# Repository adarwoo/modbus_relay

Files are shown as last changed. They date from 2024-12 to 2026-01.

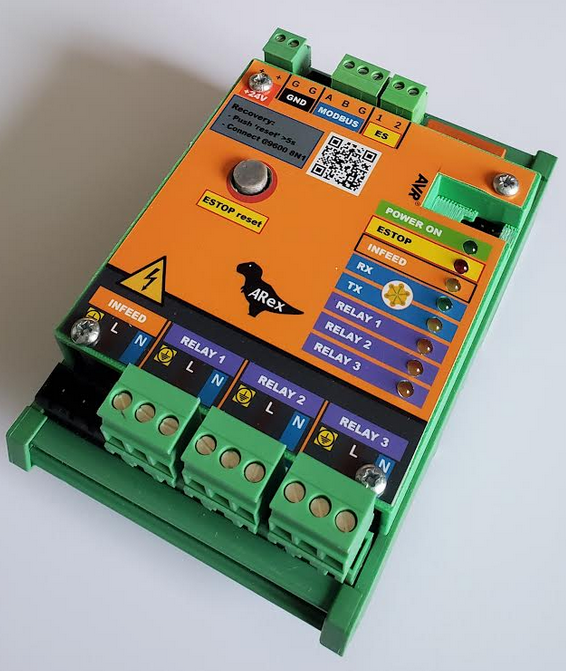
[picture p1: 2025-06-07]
cad/pictures/assembled view real.png

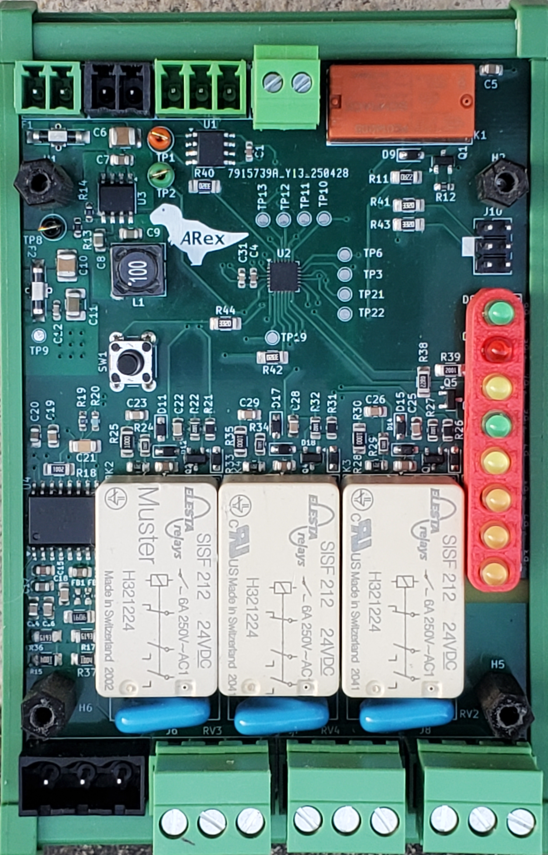
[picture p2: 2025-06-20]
cad/pictures/estop relay.png

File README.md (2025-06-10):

# Modbus Relay with EStop  #

## Introduction
This project features is a MODBUS RTU relays controller, which includes failsafe mode and an EStop.
It is aimed for industrial systems such as a CNC or equivalent.

The project comes complete with documentation, schematic, PCB, 3D part, artwork and source code.

For operational documentation, please check the complete [User Manual](docs/user_manual.md)

---

## Features summary

1. Standard DIN Rail mountable PCB
2. 3 relays - 9.4A 250VAC per output
3. Operational integrity minded
   * Uses a safety relay with force conduits and read back
   * Infeed voltage measurement with acceptable range
   * Communication watchdog
4. EStop management
   * Used for failsafe of the relay operation
      * Relay failure
      * Infeed voltage out-of-range
      * Communication loss
   * Externally controlled
     * Pulsed EStop
     * Resetable
     * Terminal
6. Operational statistics
   * Number of cycles
   * Running time
   * Fault codes

## Presentation of the hardware

<div style="text-align: center; position: relative;">
  
  
</div>

At the core of the relay is an AVR Tiny3227, an automotive grade MPU designed for harsh environment.
The MPU is clocked using the internal calibrated RC clock at 20MHz.

The relays are SISF brand used in safety critical applications.
They feature a forced conduit (so all contacts are driven by the same bar) and a dedicated read-back contact.
This allow validating the correct relay operations.
The relay are driven by small MOSFET. The read back features a contact scrubbing circuit as recommended by the manufacturer.

The modbus interface uses a RS485 driver LTC1785A (which features short protection) and transient suppressors.

The relay output features MOV suppressors for inductive loads.

The PCB can be placed in a DIN Rail PCB mount. 4 mounting screws can also be used.
A 3D cover is available to cover the whole PCBs. Together with the DIN rail mount assembly, the module should comply with IP2X.

### CAD files

The following files are available:
 * The [schematic](hw/modbus_relay.kicad.sch) edited with *KiCAD 9.1*
 * The [PCB](hw/modbus_relay.kicad.pcb) edited in *KiCAD 9.1*
 * The [BOM](hw/BOM.md) edited in *KiCAD 9.1*
 * The [Front plate artwork](hw/front_plate_graphics.svg) edited in LibreOffice Draw
 * [The front plate STL file](cad/Front%20Plate.3mf)
 * [LED holder STL file](cad/leds_spacer.STL)
 * [Spacer columns STL file](cad/3mm%2016mm.STL)
 * [Flex swtich membrane](cad/Flex%20switch%20membrane.STL)
 * [Flex retaining holder](cad/Flex%20Holder.STL)

For printing instructions, refer to [Printing the Files](#printing-the-files).

#### Printing the files

 * The case was printed in mate green PLA with PLA support material for the AVR port.
 * The flexible switch was printed in TPU.
 * The holder in black PLA.

#### Printing the front plate

 * The front was printed on an adhesive vinyl sticker at max resolution then cut to size.

> [!Note]
> You may need to adjust the dimension to account for non-linearity of the printer.

## Presentation of the software
The software is build on top of a small framework revolving around a simple reactor pattern.
The reactor allow for an arbitrary function to be notified from any context, and will execute when the CPU become available.
A simple priority system allow for reactor functions to be called in priority (to process data in a register).

A dedicated reactor pin allows measuring the worse compute time for any reactor function, which in turn, determine the worse
case latency. This allow garanteeing a real time operation throughout.
As such, the system does handle all asynchronous events in realtime with no delay, including all Modbus transaction, even at 115200 Bauds.
The jitter on the RS485 is almost null, and all replies are instantanous (4ms delay to allow for proper end of frame detection).

A python scripts is used to generates the final source for the modbus functions.

> [!TIP]
> This project could be reused for other Modbus devices. A modbus interface generator is provided that makes adding modbus commands simple.

## Application software
The application software is written in C++23 as it uses meta programming, constant expressions and concepts for efficient code.<br/>
A <i>docker</i> file is provided to create a build environment.</br>
The code fits the 32Kb flash space with plenty spare.

For build instructions, see [How to Build](#how-to-build).

## Hardware
The schematic and PCB have been edited in KiCad 9 and are supplied too.

## How to build
A docker container file is provided to recreated a full build environment.<br/>
The application can also be built in Microchip studio.<br/>
You will need a Linux shell, or WSL shell in Windows.
The tool 'gitman' is required as well as Docker. (docker-ce or else).

### Steps
```bash
# Clone this repo
$ git clone https://https://github.com/adarwoo/modbus_relay.git
$ cd modbus_relay
# Optional - install gitman
$ pipx install gitman
$ gitman update
$ make NDEBUG=1 # Optional, add ARCH=attiny1624 to suit you device
```

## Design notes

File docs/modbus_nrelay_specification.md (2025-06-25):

# ✅ Specification Requirements for Modbus N-Relay Device with EStop

## 1. Mechanical & Electrical Specifications

### 1.1 Relay and Voltage Ratings
- **SR-001**: The device shall support up to 3 relays, each rated for a maximum of 9.4A at 250V AC/DC.
- **SR-002**: The infeed voltage shall not exceed 240V (AC or DC).
- **SR-003**: The device power supply input shall operate between 15VDC and 30VDC.

## 2. Modbus RTU Interface

### 2.1 Communication
- **SR-004**: The device shall communicate over RS485 using Modbus RTU, supporting baud rates from 300 to 115200.
- **SR-005**: The communication parameters (Slave ID, baud rate, parity, stop bits) shall be configurable only in recovery mode via Modbus function 16 (Write Multiple Registers).
- **SR-006**: The device shall support Modbus function codes: 01 (Read Coils), 05 (Write Single Coil), 15 (Write Multiple Coils), 03 (Read Holding Registers), 04 (Read Input Registers), 06 (Write Single Register), 16 (Write Multiple Registers) only where specified.

### 2.2 Coil Operation
- **SR-007**: The relays shall be indexed from 0 (Relay 1) to 2 (Relay 3) in coil registers.
- **SR-008**: The device shall treat a coil written with 0xFF00 as ON (closed) and 0x0000 as OFF (open).
- **SR-009**: The failsafe state of each relay shall be OFF (open).
- **SR-010**: Writing to a disabled or faulty relay via function 05 or 15 shall return a slave device failure (code 4).

## 3. Safety & Monitoring

### 3.1 EStop Conditions
- **SR-011**: The device shall open all relays and block Modbus control when in any EStop condition.
- **SR-012**: The EStop condition shall be triggered under the following conditions:
  - Application crash
  - Power supply failure
  - Relay fault
  - Incorrect or out-of-range infeed voltage
  - Communication loss (based on watchdog timeout)
  - Modbus-issued EStop command
- **SR-013**: The device shall support 3 types of Modbus-triggered EStops:
  - Pulsed (resettable immediately after 4s)
  - Resettable (manual reset via push button)
  - Terminal (reset only via power cycle)

### 3.2 Infeed Voltage Monitoring
- **SR-014**: The device shall support configuration of acceptable voltage range between 10V to 300V (in 1/10V units).
- **SR-015**: The device shall support configuration of expected voltage type (AC 50Hz, AC 60Hz, or DC).
- **SR-016**: If voltage type or range is incorrect, the device shall enter an EStop state.
- **SR-017**: The infeed voltage type shall be reported as:
  - 0: No valid voltage (<10V)
  - 1: DC detected
  - 2: AC detected

### 3.3 Watchdog
- **SR-018**: If no Modbus command is received within the configured watchdog timeout (1–65535 seconds), the device shall trigger an EStop.
- **SR-019**: The watchdog timeout shall be configurable via holding register 40020.

## 4. Diagnostics & Statistics

- **SR-020**: The device shall store the cause and a diagnostic code for the most recent EStop event in registers 30016 and 30017, respectively.
- **SR-021**: Each relay shall maintain a counter of activation cycles (registers 30026, 30029, 30032).
- **SR-022**: The last, highest, and lowest measured infeed voltage shall be reported via input registers (30013–30015), with the ability to reset via register 40102 (write 0xAA55).

## 5. LED Behavior

- **SR-023**: On boot, all LEDs (except Modbus TX) shall turn ON for 2 seconds to test functionality.
- **SR-024**: EStop LED shall reflect fault state:
  - Off: Normal
  - On: Terminal EStop
  - 2Hz Flash: Resettable EStop
  - 2s Flash: Pulsed EStop
- **SR-025**: The Infeed LED shall:
  - Be OFF if voltage < 10V
  - Flash slowly if under-voltage
  - Flash with long ON, short OFF if over-voltage
  - Be ON if voltage is within range
- **SR-026**: The Modbus RX LED shall flash on activity or recovery mode, and TX LED shall flash only on outgoing traffic.
- **SR-027**: Each Relay LED shall:
  - Be ON if the relay is closed
  - Be OFF if open
  - Flash at 2Hz if the relay is faulty
  - Flash slowly if disabled

## 6. Relay Configuration

- **SR-028**: Each relay shall be individually configurable as:
  - Enabled with no filtering (`0`)
  - Enabled with a debounce filter between 100–60000 ms
  - Disabled (`0xFFFF`)
- **SR-029**: Configuration changes to relays shall require a device reset to take effect.

## 7. Recovery Mode

- **SR-030**: Recovery mode shall be activated by pressing the reset button for >3s.
- **SR-031**: In recovery mode:
  - Slave ID = 248
  - Baud rate = 9600
  - Serial = 8N1
- **SR-032**: Recovery mode shall maintain ongoing relay states and allow modification of communication settings.

## 8. Device Identification & Control

- **SR-033**: The device shall expose a unique Product ID (register 30001), HW version (30002), and SW version (30003).
- **SR-034**: The relay count (register 30004) shall match the actual number of relays supported (1–32).
- **SR-035**: The device shall support the following write-only control commands via register 40101–40106:
  - Set/Reset EStop
  - Zero measurements
  - Flash all LEDs
  - Factory reset
  - Exit recovery mode
  - Reset device

## 9. Fault Handling

- **SR-036**: If a relay position check fails, the EStop shall be triggered in terminal mode.
- **SR-037**: A faulty relay shall be identifiable via its LED flashing at 2Hz and input register status.

## 10. Default Settings

- **SR-038**: Default configuration on factory reset shall include:
  - Relay 1–3: Enabled, no filter
  - Watchdog timeout: 0 (disabled)
  - Infeed voltage type: AC 50Hz
  - Voltage thresholds: Lower = 100, Upper = 3000 (1/10V)

## 11. Open Requirements for Review

- **[OPEN-REQ-01]**: Behavior if voltage is exactly on threshold value (e.g., 100 or 3000). Should this be considered in-range or out-of-range?
- **[OPEN-REQ-02]**: If recovery mode times out or can persist indefinitely.
- **[OPEN-REQ-03]**: Definition of debounce filtering algorithm for relay inputs.

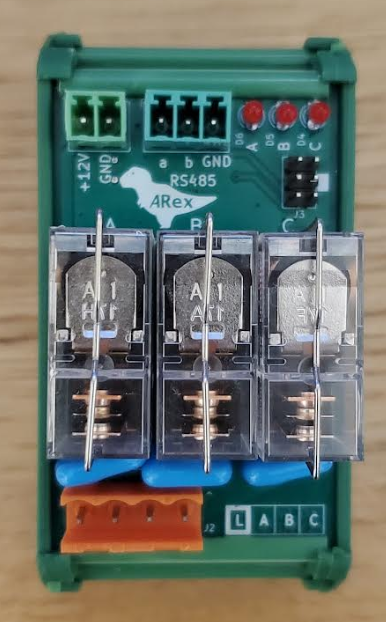
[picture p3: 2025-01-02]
cad/pictures/front.png

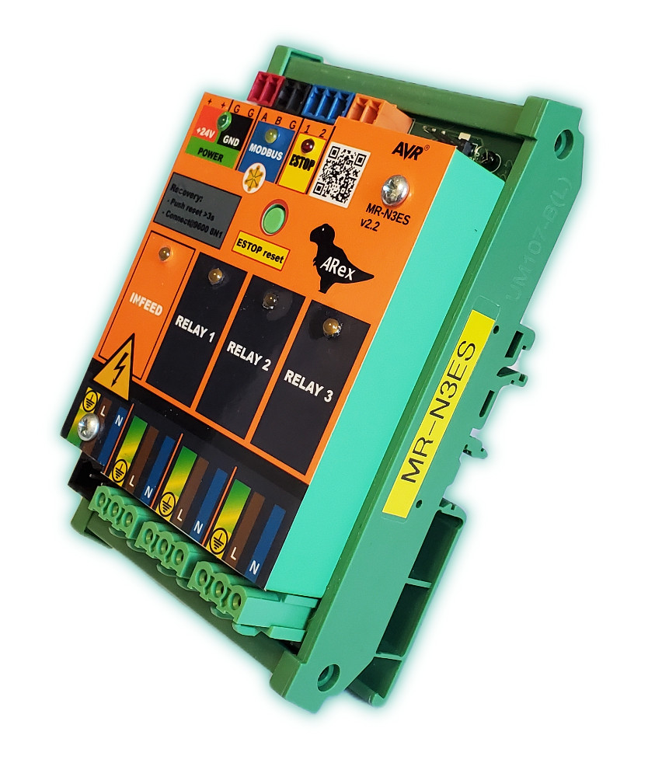
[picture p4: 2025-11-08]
docs/brochure view.jpg

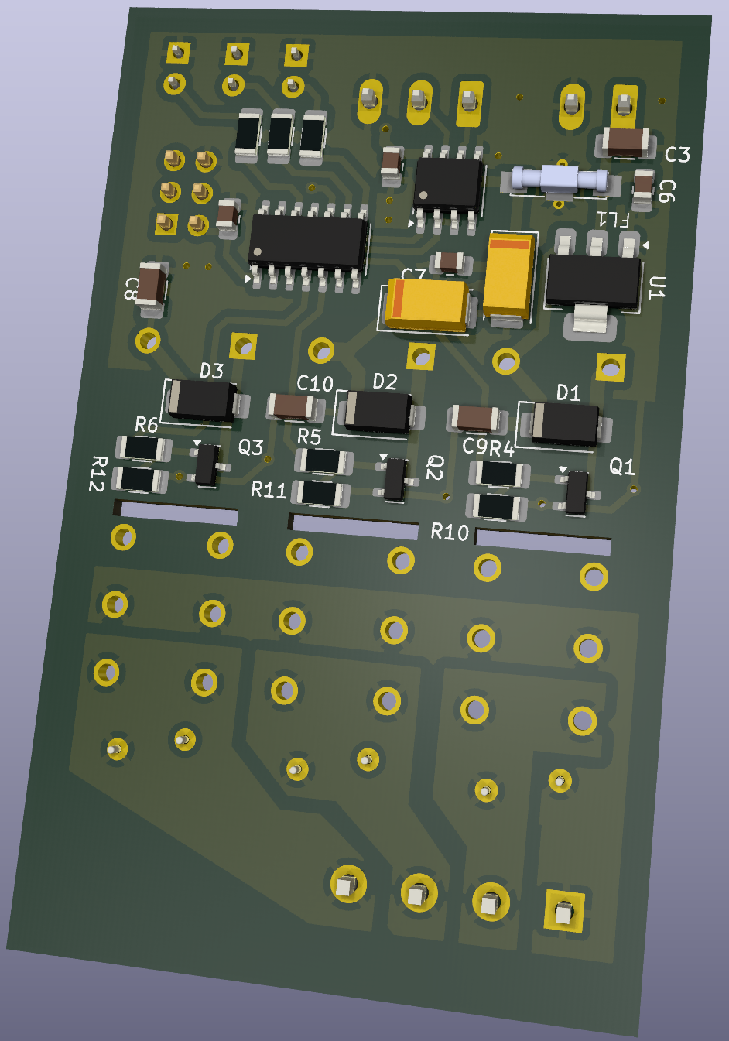
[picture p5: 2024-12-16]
cad/pictures/back.png

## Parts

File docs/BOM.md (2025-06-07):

| Reference | Qty | Value | Footprint |
|---|-----|---|---|
| C1, C4, C12 | 3 | 100n | 0603 |
| C5, C8, C14, C19, C24, C27, C30 | 7 | 1u | 0805 |
| C6, C10 | 2 | 10u 50v | 1210 |
| C7 | 1 | 220nF | 0805 |
| C9, C16, C18, C22, C23, C25, C26, C28, C29 | 9 | 100n | 0805 |
| C11 | 1 | 47u | 1210 |
| C13, C15, C17, C20 | 4 | 1n | 0805 |
| C21 | 1 | 100n | 1206 |
| C31 | 1 | 10n | 0603 |
| D1, D2, D3 | 3 | Orange 10mA | 3mm straight |
| D4, D8 | 2 | Green 10mA | 3mm straight |
| D5 | 1 | Red 10mA | 3mm straight |
| D5, D7 | 2 | Yellow 10mA | 3mm straight |
| D9, D10, D11, D12, D13, D14, D15, D16, D17, D18 | 10  | BAS16 | SOD-323 |
| D19 | 1 | SM712 | SOT-23 |
| FB1, FB2, FB3 | 3 | Ferrite | 0603 |
| FB4, FB5 | 2 | Ferrite | 0603 |
| J2 | 1 | 3 Pins Screw Header | Pitch 3.81mm<br/>Phoenix MC |
| J4, J9, J11 | 3 | 2 Pins Screw Header | Pitch 3.81mm<br/>Phoenix MC |
| J5, J6, J7, J8 | 4 | Screw_Terminal_01x03 | Pitch 5.08mm<br/>Phoenix MSTB |
| Q1, Q2, Q3, Q4, Q5 | 5 | BSS138 | SOT-23 |
| R1, R2, R3, R4, R5, R6, R7, R8 | 8 | 680 | 1206 |
| U1 | 1 | LT1785AxS8 | SOIC-8 |
| U2 | 1 | ATtiny3227-M | QFN-24 |
| U3 | 1 | LMR33630ADDA | HSOP-8 |
| U4 | 1 | AMC3330 | SOIC-16W |
| SW | 1 | Tactile switch | 6mmx6mm 9.5mm eg TL1105BF160Q |
| F1-F2 | 2 | Murata NFM61R | SMD |
| J10 | 1 | Header 2x3 | Pitch 0.1" |
| RV1-RV4 | 4 | MOV 471K | Pitch 7mm |
| H1-H4 | 4 | Spacers 3mm / Ø 16mm | To print |
| K2-K4 | 3 | Relay Muster SiSF212 24V| Through |
| K1 | 1 | Relay 5V DPDT Shrack | PE014005 |

Don't forget to add the Phoenix plugs for FB1 - FB5.

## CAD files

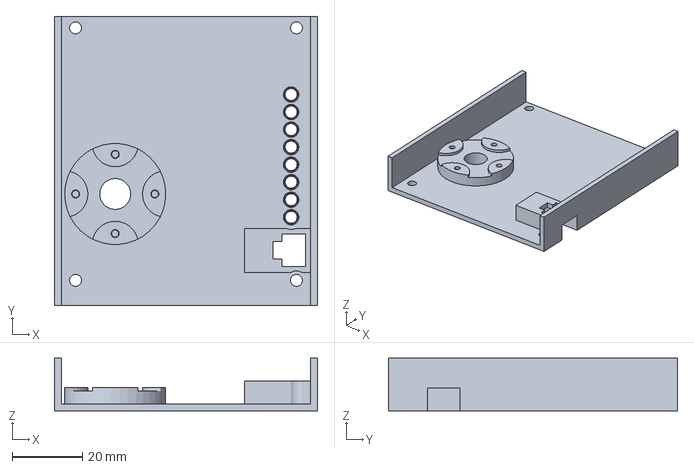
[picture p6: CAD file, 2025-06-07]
cad/3d/Front Plate.3mf
75.0 x 82.4 x 15.0 mm

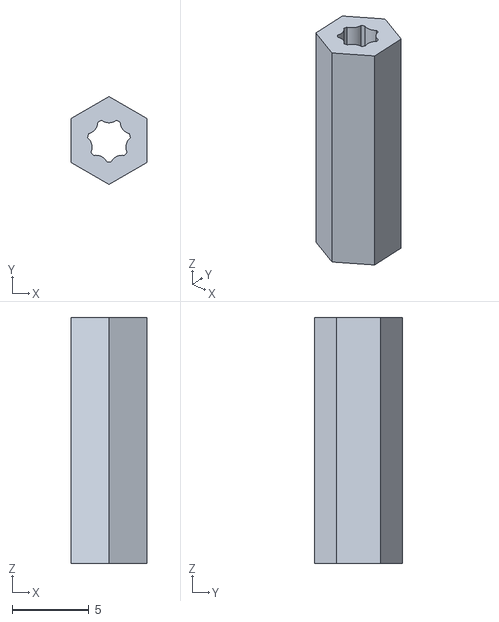
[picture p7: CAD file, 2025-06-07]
cad/3d/3mm 16mm.STL
4.95 x 5.72 x 16.0

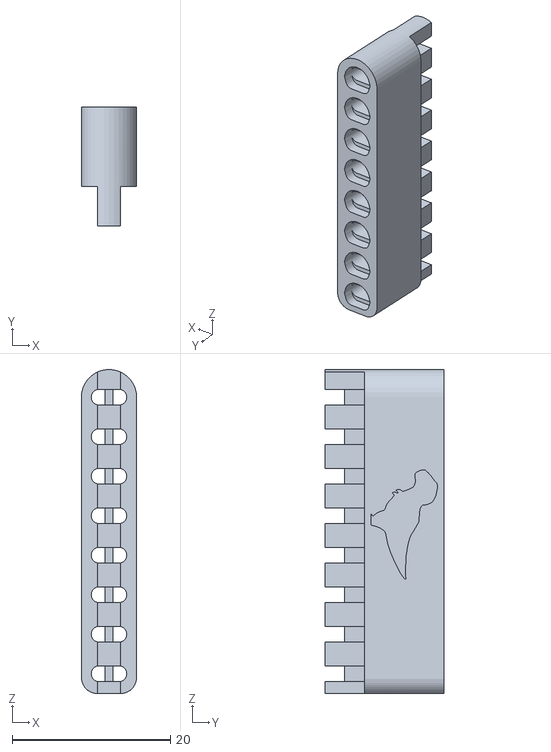
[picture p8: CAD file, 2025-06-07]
cad/3d/leds_spacer.STL
7.00 x 15.0 x 41.0

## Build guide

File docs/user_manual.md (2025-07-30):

# Modbus Relays Device with EStop <br/>**User manual**

## Introduction

This project features a MODBUS-RTU relays device with emergency stop, infeed measurements, monitoring and failsafe modes.
It is aimed at industrial systems such as a CNC or equivalent.

This document provides a description for the operations of the device.

### Device identification
The device identification is ARex_R3.
The hardware and the software are released together, the github TAG references this design uniquely.

### Features summary
This relay goes beyond a single Modbus relay and is packed with features:

1. Standard DIN Rail mountable PCB
2. 3 relays - up to 9.4A @ 250V per output
   * Individual filtering for ON and OFF cycles for each relay
3. Operational integrity minded
   * Uses safety relays with forcibly guided contacts, 10.10<sup>6</sup> operations, re-inforced isolation and position read back
   * Galvanically isolated infeed voltage measurement with acceptable range
   * Communication watchdog
4. Emergency Stop (EStop) management
   * Used to safe guard relay operations
      * Relay failure
      * Infeed voltage out-of-range
      * Communication loss
      * Application crash/corruption
   * Can be controlled by the Modbus server
     * Pulsed EStop
     * Resetable EStop with a push button
     * Terminal EStop for terminal cases
5. Operations statistics
   * Number of cycles
   * Running time
   * Fault codes
6. Diagnostics over Modbus
   * Infeed highs and lows
   * Infeed type and level
   * EStop causes and diagnostic

## Operations overview
Operations are performed over an RTU communication bus.<br/>
A push button is also featured with limited use:
* to reset EStops (when possible)
* to activate a recovery mode by placing the relay in a known state, allowing writting communication registers
<br/>
This section describes how to configure and operate the device, including its default settings, configuration mode, and reset process.

### System startup

The device starts with the EStop active (failsafe on power loss).
The device does a self-check, and starts measuring the infeed.
If all conditions are correct, the EStop is cleared. (the led turns off).
If a persistent fault is detect, the device goes in EStop.

### Relay polarity and failsafe position
The relays failsafe position is 'OFF' - that is - the contact is opened.
If the device loses power, the relays immediatly open the contacts - turning off the load.
A security prevents turning them back-on in case of crash.

The control of the relay always operates with a positive polarity, so writing '1' will close the relay - and energise the load.

### Basic operations
The relay works like any Modbus coil based devices, by writting the coil registers.
Each relay can be controlled individually, turned ON, OFF or inverted.
The relays can also be controlled in bulk.

See [Coil registers](#Coil_registers) chapter for details operations.

### Relay filtering
Filtering can be added to the relays to control the minimum ON and OFF cycles duration.
An ON filter of 2 sseconds means that the relay ON cycle will never be shorter that 2 seconds.
The same goes for the OFF filter, which guarantees a minimum duration of the OFF cycle.
Any command received during a filtered cycle will be accepted and will become the next relay state once the cycle is complete and unless overwritten by another command.

When toggling the relay, it is the projected state (the state at the end of the current cycle) that is toggled.

**Example**: a relay has an ON minimum cycle time of 5 seconds and no filter for the OFF.
* It receives a ON command. It turns ON. The cycle starts.
* Within 1 second, an OFF command is sent. This command become the next relay state, but the state of the relay remains unchanged.
* After 4 seconds, the relay turns off.
* A new ON is sent, the relay turn ON right away since the OFF cycle is not filtered.
* Within 1 second, an OFF is sent. The relay stays on.
* Another 1 second later, an ON is sent. The relay is already ON. The next state is the current state, so nothing happens.
* Another 4 seconds later, an OFF is sent. The relay turns OFF immediatly, because the ON cycle is now 6 seconds, less than the ON cycle filter duration.

> [!WARNING]
> When reading the status of a relay, the actual physical position is returned, not the projected position.

## System Health Monitoring

This device distinguishes itself from simpler models by its ability to monitor the health of the system, and to halt operations by opening an EStop relay.

The active elements being monitored and/or mesured are:
1. Device integrity
2. Modbus communications
3. Infeed voltage, that is the upsteam supply voltage
4. Proper operation of the relays

### Device integrity monitoring

The device monitors itself to guarantee proper execution.
All memories are verified:
* The flash memory integrity is verified at every boot
* The RAM is tested once on boot-up
* The EEprom storage contains a checksum and is reformatted if a corruption is detected
* The CPU power supply is monitoring by the brown-out-detector to safeguard the EEprom
* A failsafe exist which activates the EStop if the power supply was to fail
* The execution is monitored; an application crash will EStop the device

Any managed failure leads to the EStop being activated.

### Modbus communication monitoring

The device monitors the activity of the Modbus RS485 link, and through this, the health of the Modbus server.
This monitoring activity can be configured to trigger an resetable EStop.

> [!NOTE]
> The bus is considered active if commands addressed to the device are received at least once in the configured watchdog duration.

> [!IMPORTANT]
> For good operation, it is recommended to read the register 30009 (Status) periodically, like every second.
> This will keep the Modbus communication active, and all the Modbus master to detect an EStop by the relay device.

### Infeed monitoring

The module measures the infeed voltage of the relay and the type of infeed (AC vs DC).
The AC measurement is the approximate RMS value. The input signal is expected to be a 50Hz or 60Hz supply.

The last measured value, but also the lowest and highest measured values are accessible over the Modbus network.
Additional Modbus registers allow resetting those values during investigations.

The measurement can be used to trigger an EStop on:
1. Incorrect type (AC vs DC) of the infeed
2. Reverse polarity of the DC (The negative must be connected to 'N' and the positive to 'P').
3. Undervoltage : The infeed voltage is lower than a configured threshold
4. Overvoltage : The infeed voltage is higher than a configured threshold

When an infeed defect is detected, the device will open the EStop relay.<br/>
A reverse polarity is terminal.

### Relay health monitoring

All the relays are equiped with a position verification which is backed mecanically using a forced conduit.
If a relay fault is detected (open or close):
* the relay coil is de-energized, and the relay should become opened.
* the ESTop condition is trigggered in terminal mode where only a power cycle can clear the condition.

The faulty relay can be isolated by disabling it in the configuration, but it should be replaced.

### External EStop command

The modbus master can issue an EStop command. This external EStop condition can be:

* Pulsed EStop. The system will halt, but can be resumed right after
* Resetable EStop. The EStop condition is reset by pushing the 'EStop reset' push button.
* Terminal. Only a power cycle can clear the condition.

## Locate mode
The mode allows locating an relays device in setups with more than one.
When activated, the LEDs will alternate every seconds between:
 * all LEDs flash fast for 1 seconds
 * all display their normal state for the next 1 second
The locate mode is activated by a dedicated Modbus command.
It is ended by either a Modbus command, or by pressing the 'EStop reset' push button.

## Recovery mode
The recovery mode is used to recover a device with unknown setting, but also, to make changes to the communication paramters.
The recovery mode is entered by pressing the 'EStop reset' push button until the Modbus LEDs flash fast (around 3 seconds).<br/>
In these situations, the following procedure can be used:

1. Start the RelayGuardian application
2. Make sure the communication port is properly setup in the RelayGuardian
 * The connection icon should be OK
 * Issue a scan command in the RelayGuardian to make sure the RS485 adapter sends the data (Red LED)
 * If this is not the case, check the modbus is plugged correctly in the PC and the comm port is the correct one
3. If devices are identified during the scan, click the 'locate' icon one device at time to see if it is the right one
4. Else start the recovery
  1. Push the relay 'EStop reset' push button for > 3s
   * The Modbus LEDs are flashing
   * The communication values have been temporary reset to:
      | Configuration     | value             | Explanation                                    |
      |-------------------|-------------------|------------------------------------------------|
      | **Slave ID**      | `248`             | This value is reserved in the modbus standard, so no other devices should use it |
      | **Baud rate**     | `9600`            | The device talks at 9600 by default            |
      | **Serial setup**  | `8N1`             | 8bits, no parity and 1 stop bit                |

  2. In the 'Relay Guarian' application, click the 'Recovery' button
  3. Confirm proper connection
  4. In the 'RelayGuardian', click the 'Locate' button. All LEDs of relay module should be flashing fast!
   . The module is being reovered.
  5. Stop the device location mode
5. Go to the settings tabs, check the configuration, or adjust.
6. Hit the 'Synchronize' button in the relay guardian to match the relay configuration.
   . The guardian takes the relay out of recovery mode automatically.
   . You're all set!

> [!NOTE]
> The recovery mode maintains on-going relay operations.

> [!TIP]
> The recovery mode can also be ended by pressing the 'EStop reset' push button for another 3s.

## EStop mode

The device EStop relay opens the circuit when the device is in EStop condition.

The EStop condiiton is the result of:
* Detecting a internal failure (relay, crash, infeed, supply etc..)
* Through external command over Modbus

The EStop condition can be:
* Reset automatically (pulsed EStop)
* Manually reset
* Remotely reset

In all cases, the EStop condition can be read over the Modbus network.

> [!IMPORTANT]
> When the device is in both locate and EStop mode, the first push on the EStop reset clears the locate mode and the second clears the EStop.

### Relays in EStop

When the EStop is triggered by an internal condition, all the relays are **opened** (pending filtering) and no longer respond to Modbus commands (without errors).
A reset the EStop is only possible if the root cause has been cleared.
<br/>
When the EStop is triggered externally, the relays are not impacted, and it is still possible to command the relays over the modbus network.
<br/>
Example: As the infeed drops to 0 (below the threshold), all relays are opened and the EStop is activated. It is only possible to reset the EStop once the infeed voltage is back to normal.

## LEDs

The module features many LED to see the device operation and faults easilty.
All LEDs serve multiple pursposes.

### Boot

During boot, for the first 2 seconds, all LEDs are lit. This allow checking for a faulty LED.
The fault LED remains on if a persistent fault condition is detected during the auto-test.

### Locate function
To help locate a relays device, a Modbus locate command can be sent.<br/>
See [Locate mode](#Locate_mode)

The EStop reset push button can be pressed to end the locate cycle, or a new Modbus command can be sent.

For detailed LED states, see:
- [EStop LED](#estop-led)
- [Infeed LED](#infeed-led)
- [Modbus LEDs](#modbus-leds)
- [Relay LEDs](#relay-leds)

### Recovery mode
This only affects the Modbus Tx and Rx LEDs which flash at 2Hz in sync.

### EStop LED

The fault LED state is as follow:

| State | Description |
|---|---|
| Off | Normal operations |
| On | The device is terminated. A hard reboot is required. If the termination was caused by a failing relay, the correspond relay LED will flash at 2Hz |
| Flash at 2Hz | Fault detected. The fault can be cleared by pressing the ESTOP reset button.<br/>Another LED will synchronously blink to point to the fault.<br/><ul><li><b>Infeed LED</b>: Infeed fault, under or over</li><li><b>TX LED</b>: Modbus watchdog</li></ul>
| Flash once for 2s | A pulsed EStop condition was received from the modbus master |

When an EStop is is progress, a source LED is flashing fast to point to the source:
  * If a relay is at fault, the corresponding relay LED flashes
  * If the infeed supply is at fault, it will flash. Note, the LED will flash (Long on short off) it a voltage is detected.
  * The modbus Rx LED will flash to indicate the EStop was triggered remotely

### Infeed Led

The infeed LED provides visual information about the infeed voltage.

| State | Description |
|---|---|
| Off | Infeed voltage is < 10V (AC+DC) |
| On | Infeed voltage detected, and within configured range |
| Flash . . | Voltage detecting, but below the configured threshold |
| Flash _ _ | Voltage detecting, but over the configured threshold |
| Flash at 2Hz | Along with the EStop. A infeed fault was detected. |

> [!CAUTION]
> The Infeed LED is for indication only. ***You must assume voltage is present at all times***.

### Modbus LEDs

The modbus LEDs show activity on the Modbus RS485 network.

Both LEDs are overriden during boot, recovery and identification modes.

* The Rx LED shows received data on the RS485 bus. The data may or may not be addressed at the device
* The Tx LED shows data being sent from the device (as the device replies to the master)

### Relay LEDS

Each relay have a dedicated LED. The LED reports the status of the relay is corresponds to.

The LED status is as follow:

| State | Description |
|---|---|
| Off | The relay is in the OFF state |
| On | The relay is in the ON state  |
| Flash | The relay is faulty |
| Blink | Relay is disabled |

## Modbus communications and registers

The product uses [ModbusRTU over a half-duplex RS485](https://www.modbus.org/docs/Modbus_over_serial_line_V1.pdf).
It allow communication up-to 115200 baud to the relays device.

The Modbus registers are grouped into:
- [Coil Registers](#coil-registers)
- [Input Registers](#input-registers)
- [Holding Registers](#holding-registers)
- [Device Control Registers](#device-control-registers)

For communication settings, see [Communication Settings](#communication-settings).

> [!NOTE]
> By convention, all relays are indexed from 0.
> Therefore, the device relay label 'Relay 1' is indexed at 0. The relay '2' is indexed at 1 etc.

### Coil registers

The relay coils can be accessed from 0 (Relay 1) upto relay 31.
Coils can be written and read at will.

The device supports the following function code:
 * **01**: [Read coils](https://www.modbustools.com/modbus.html#function01)
<br/>Read from 1 to 32 contiguous status of coils.
<br/>Coils in the response message are packed as one per bit of a byte, 1=On and 0=Off.
<br/>If the requested quantity of coils are not a multiple of 8, zeros are padded in the final byte.
 * **05**: [Write single coil](https://www.modbustools.com/modbus.html#function05)
<br/>Write a single output to either On (1) or Off
 * **15**: [Write multiple coils](https://www.modbustools.com/modbus.html#function15)
<br/>Force each coil in a sequence of coils to either On or Off

> [!IMPORTANT]
> Relays operations are not impacted by the EStop
> Unless a relay is faulty or disabled, a command of that relay will always be executed, but could be delayed by one of the relay cycle filters

> [!WARNING]
> Attempts to write individually a disabled relay with the function <b>05</b> will generate a <i>slave device failure (4)</i> error.
> Attempts to turn ON a disabled or faulty relay as part of the function **15** will also generate a <i>slave device failure</i> error.
> You can still use function **15** providing that the faulty/disabled relay is commanded to OFF.

#### Detail of the function 05 : Write single coil

The following values can be used:

| Value | Meaning |
|---|---|
| 0x0000| This specific 16-bit value is the Modbus standard representation for "OFF". |
| 0xFF00| This specific 16-bit value is the Modbus standard representation for "ON" when writing to a coil. |
| 0xAA00| This value toggles the coil at then end of the cycle |

### Input registers

Input registers are read-only registers used to report information about the device.
The registers have been grouped so they can easily be accessed.
Reserved values reads as 0, therefore, it is possible to read them all at once.

Only the function **04**: [Read input registers](https://www.modbustools.com/modbus.html#function04) is supported to read registers.

> [!WARNING]
> Make sure to issue function 04: Read input registers when reading input registers and not function ~~**03: Read Holding Regsiters**~~, as the memory of both types overlaps.

#### Device Identification

This registers provides details about the device in use.

| Modbus Address | Hex value | Access | Description | Value(s) |
|---|---|---|:---:|---|
| 30001 | 0x0000 | R | Product ID | MSB=device Identification code <sup>1</sup><br/>LSB=Number of relays <sup>2</sup> |
| 30002 | 0x0001 | R | HW version | MSB=minor, LSB=major |
| 30003 | 0x0002 | R | SW version | MSB=minor, LSB=major |
| 30004 | 0x0003 | R | Number of relays | UINT16<br/>1-32 |
| 30005–30008 | 0x0004–0x0007 | R  | *Reserved* | |

* <sup>1</sup> EStop relay code=0x37. Simple modbus code=0x36.
* <sup>2</sup> A 3 relays device would be 0x3703. A 32 relays device would be 0x3720.

#### Status & Monitoring

| Modbus Address | Hex value | Access | Description | Values |
|---|---|---|---|---|
| 30009 | 0x0008 | R | Current status | <ul><li><b>0</b>: Device is operational</li><li><b>1</b>: Device is in EStop.<br/>A reset is possible</li><li><b>2</b>: Device in terminal EStop</li></ul> |
| 30010 (+1) | 0x0009 (+1)| R | Running minutes | UINT32<br/>0-2<sup>32</sup>-1 |
| 30012 | 0x000B | R | Actual infeed voltage type  | Reports the type of infeed voltage detected<br/><ul><li><b>0</b>: Measured AC/DC voltages are below 10V</li><li><b>1</b>: DC</li><li><b>2</b>: AC</li></ul> |
| 30013 | 0x000C | R | Current infeed voltage | 1/10 volts<br/>0-3000 |
| 30014 | 0x000D | R | Infeed highest voltage | Returns the lowest measured infeed voltage until now in 1/10th of volts.<br/>This value can be reset with the command: - [40102 - Reset measurements](#device-control-registers) |
| 30015 | 0x000E | R | Infeed lowest voltage | Same as 30014, but returns the lowest |
| 30016 | 0x000F | R | Last or on-going EStop root cause | <ul><li><b>0</b>: Normal<br>No EStop occured since power-up</li><li><b>1</b>: Relay<br/>A relay fault as detected<br/></li><li><b>2</b>: Modbus<br/>The communication watchdog reported a lack of communication</li><li><b>3</b>: Infeed voltage type<br/>An ncorrect voltage or voltage type was detected<br/></li><li><b>4</b>: Infeed voltage under<br/>The voltage has gone below the configured threshold</li><li><b>5</b>: Infeed voltage over<br/>The voltage has gone over the configured threshold</li><li><b>6</b>: Command<br/>A modbus command was issued to lace the device in EStop</li><li><b>7</b>: Application crash<br/>The device is recovering from an application crash</li></ul><br/>This register and the diagnostic code operate as a pair. They are not cleared when the EStop is reset, allowing for post crisis diagnostic, or checking the cause of pulsed resets. |
| 30017 | 0x0010 | R | Diagnostic code | Diagnostic code of the EStop condition<br>The content value depends on the EStop root cause:<ul><li><b>normal</b><br/>0</li> <li><b>Relay</b><br/>Holds the faulty relay zero based index number.</li> <li><b>Modbus</b><br/>The timeout in seconds</li> <li><b>Infeed (all of them)</b><br/>0xFFFF if the voltage type is incorrect, else the triggering voltage in 1/10V</li> <li><b>Command</b><br/>Contains the EStop control value</li> <li><b>Application crash</b><br/>0xDEAD</li></ul>|
| 30018–30024 | 0x0011–0x0017 | —  | *Reserved* | |

#### Relay Diagnostics & Statistics

The status of each relays is accessible, and well as their indivual number of cycles.
A cycle is defined as a change of a relay state during operation (exclude powerloss transitions).
<br/>
The address space is structured to expand up to 32 relays for other variants of devices.

| Modbus Address | Hex value | Access | Description | Values |
|---|---|---|:---:|---|
| 30025 | 0x0018 | R | Relay 1 diagnostic | 0=OK<br/>1=Faulty<br/>2=Disabled |
| 30026-30027 | 0x0019-0x001A| R | Relay 1 number of cycles | UINT32<br/>0-2<sup>32</sup>-1 |
| 30028 | 0x001B | R | Relay 2 diagnostic | 0=OK<br/>1=Faulty<br/>2=Disabled |
| 30029-30030 | 0x001C-0x001D| R | Relay 2 number of cycles | UINT32<br/>0-2<sup>32</sup>-1 |
| 30031 | 0x001E | R | Relay 3 diagnostic | 0=OK<br/>1=Faulty<br/>2=Disabled |
| 30032-30033 | 0x001F-0x0020| R | Relay 3 number of cycles | UINT32<br/>0-2<sup>32</sup>-1 |

> [!WARNING]
> Reading passed the last supported relay will generate a **illegal data address** error.

> [!TIP]
> For generic software, the number of available relays can be read in input registers 30004.

### Holding registers

Holding register contain values can be read or written. The hold configuration details.
They are grouped by functions.
It is possible to read all the holding registers with 1 command as the reserved values will read as one.
Writing these registers is restricted to prevent mis-behavious.

> [!WARNING]
> Reserved values cannot be written and will generate an error.

#### Supported function codes

The following function codes are supported:

* **03** - [Read Holding Registers](https://www.modbustools.com/modbus.html#function03)
<br/>Reads the values of one or more holding registers.
<br/>Commonly used to retrieve configuration or control values stored in the device.
* **06** - [Write Single Register](https://www.modbustools.com/modbus.html#function06)
<br/>Writes a single value to a specific holding register.
<br/>Used for updating configuration or control parameters.
* **16** - [Write Multiple Registers](https://www.modbustools.com/modbus.html#function16)
<br/>Writes a whole configuration group at once. This is only available for writting the communication settings.

> [!WARNING]
> Do no issue the function 04: Read input registers when reading holding registers as the memory addresses of both types overlaps.

Other functions codes such as 23 ( Read/Write Multiple Registers) are not supported.

#### Communication Settings

This group of registers allow configuring the communication settings of the relay.

> [!IMPORTANT]
> These registers are <ins>write protected</ins>.
> You must activate the 'recovery' mode to change them, by pressing the 'EStop Reset' button for more that 3 seconds.

> [!NOTE]
> Function ~~**06: Write single register**~~ is not availble for this group.
> You must use the command **16 - Write Multiple Registers**, writting registers 40001 to 40004 at once.
> Once a write is done, the device comes out of recovery mode and applies the changes right away.

| Modbus Address | Hex Value | Access | Description | Factory value | Values |
|---|---|---|---|---|---|
| 40001 | 0x0000 | RW<sup>1</sup> | device address | 44 | [1-247] |
| 40002 | 0x0001 | RW<sup>1</sup> | Baud rate selection | 5 | 0=300<br/>1=600<br/>2=1200<br/>3=2400<br/>4=4800<br/>5=9600<br/>6=19200<br/>7=38400<br/>8=57600<br/>9=115200 |
| 40003 | 0x0002 | RW<sup>1</sup> | Parity | 0 | 0=None<br/>1=Odd<br/>2=Even |
| 40004 | 0x0003 | RW<sup>1</sup> | Stopbits | 1 | 1=1 Stop bit<br/>2=2 stop bits |
| 40005–40008 | 0x0004–0x0007 | R  | *Reserved* | | |

<sup>1</sup>Writable only in recovery mode

#### Power Infeed Configuration

| Modbus Address | Hex Value | Access | Description | Factory Value | Values |
|---|---|---|---|---|---|
| 40009 | 0x0008 | RW | Infeed voltage type | 1 | 0=DC<br/>1=AC |
| 40010 | 0x0009 | RW | Infeed lower voltage threshold | 100 | 1/10 volts [100-3000] |
| 40011 | 0x000A | RW | Infeed upper voltage threshold | 3000 | 1/10 volts [100-3000] |
| 40012–40016 | 0x000B–0x000F | R  | *Reserved* | 0 | |

> [!WARNING]
> Registers 40009 to 40011 must be written together using command **16**.
> Function ~~**06: Write single register**~~ is not availble for this group.
> An illegal_data_value error (code 3) will be returned if (40011 - 40010) < 10

#### Safety Logic Configuration

Some of the monitored values can optionally control the EStop. It is also possible to set the behaviour of each relay on these optional EStop conditions.

| Modbus Address | Hex Value | Access | Description | Factory Value | Values |
|---|---|---|---|---|---|
| 40017 | 0x0010 | RW | Activate EStop on undervoltage | 0 | 0=no<br/>1=yes |
| 40018 | 0x0011 | RW | Activate EStop on overvoltage | 0 | 0=no<br/>1=yes |
| 40019 | 0x0012 | RW | Activate EStop on incorrect type of supply voltage<br>Example: AC detected with DC configured | 0 | 0=no<br/>1=yes |
| 40020 | 0x0013 | RW | Activate EStop on number of seconds without modbus frame received | 0 | 0=off<br/>[1-65535] Number of seconds |
| 40021 | 0x0014 | RW | Mask to open relays on electrical infeed fault.<br/>When a infeed fault is detected (undervoltage, overvoltage or incorrect voltage type), the projected relay state<sup>1</sup> is opened or left unchanged based on this value.<br/>A bit at 1 in the mask indicates the relay should open on a fault detection. The lsb (bit 0) masks the relay at index 0, the msb (bit 15) masks the relay at index 15 | 0 | 0-0xFFFF<br/><br/>Example:<br/>0: No relays are affected<br/>5 (binary 110): Relays at position 1 and 2 are set to open<br/>0xFFFF: All relays are set to open |
| 40022 | 0x0015 | RW | Mask to open relays on modbus communication loss fault<br/>When a loss in communication is detected, the relay projected state<sup>1</sup> is opened is left unchanged with this value. | 0 | See 40021 |
| 40023–40024 | 0x0016–0x0017 | R  | *Reserved* | | |

<sup>1</sup>The projected state is the state of a relay once the on-going filter cycle is complete

> [!WARNING]
> The registers must be written individually. The command **16** is not supported.

#### Relays Configuration

This group allow configuring the individual relays.

| Modbus Address | Hex Value | Access | Description | Factory default | Values |
|---|---|---|---|---|---|
| 40025 | 0x0018 | RW | Relay 1 config | 0=Enabled, no filter | msb bits [15-8] are for the ON filter<br/>lsb bits [7-0] are the OFF filter<br/>The value 0xFFFF disables the relay.<br/><br/>The ON and OFF filters values are given in 1/10 of seconds from 0 to 254 (0 to 25.4s)<br/><u>Example</u>: 0x0132=The On state is guaranteed to last at least 100ms, whilst the OFF state is guaranteed to last at least 50 x 1/10s = 5s after a ON. See relay operations. |
| 40026 | 0x0019 | RW | Relay 2 config | 0=Enabled, no filter | Same as relay 1 config |
| 40027 | 0x001A | RW | Relay 3 config | 0=Enabled, no filter | Same as relay 1 config  |
| 40025+N<sup>1</sup> | 0x0018+N| RW | Relay N config | 1=Enabled, no filter | Same as relay 1 config |

<sup>1</sup> N is the relay index [0..(Number of relay-1)]

> [!WARNING]
> The registers must be written individually. The command **16** is not supported.

> [!WARNING]
> Read or writing a non-supported relay will generate an error.

### Device control registers

These register share the holding registers mapping address space but are write-only.
This group of register allows controlling the EStop and the device device.

> [!NOTE]
> These registers are write only.
> The function ~~**03: Read multiple registers**~~ is not availble for this group.
> Function ~~**16 - Write Multiple Registers**~~ is not available.
> The registers must be written individually.

| Modbus Address | Hex Value | Access | Description | Values |
|---|---|---|---|---|
| 40101 | 0x0064 | W | Set/Reset the EStop | ESTOP_CTRL<br/>See note <sup>1</sup>|
| 40102 | 0x0065 | W | Zero measurements. Allow re-measuring min and max | 0xAA55  |
| 40103 | 0x0066 | W | Identify the device. Fast flash all the LEDs to identify the device | 0 = Turn off<br/>1 = Turn on |
| 40104 | 0x0067 | W | Reset configuration to factory default and reboot  | 0x178C |
| 40105 | 0x0068 | W | Exit recovery mode and apply comms settings  | 0xAA55  |
| 40106 | 0x0069 | W | Reset the device | 0xAA55  |

**Note <sup>1</sup>** : See the format below

#### EStop control

The following table documents the type **ESTOP_CTRL** used to control the EStop.

| Byte | Function | Values |
|---|---|---|
| MSB  | Type of EStop | 0x00 : Reset the EStop if possible. Returns an error if the EStop could not be reset<br/>0x11 : Pulsed EStop. Create a 4 second EStop pulse<br/>0x22 : Resetable EStop mode. The EStop can be reset by pushing the EStop reset button<br/>0xFF : Terminal EStop. Only a reset will clear the ESTop (Register 40103) |
| LSB | Diagnostic code | A code can be applied to allow investigating the cause of EStop/Reset.<br/>Values: <0-255> |

## Electrical and mecanical characteristics

For relay data, refer to the datasheet of the [SiSF2 relay](https://www.ermec.com/catalogos/2021/ELESTA/sisf2_-_en.pdf) for detailed data.
Note that both contacts of the relay are paired as one.
The key information is summ

### Electrical characteristics

| Item | Min | Max |
|---|-----|-----|
| Device supply voltage | 18 VDC | 30 VDC |
| Infeed voltage | - | 250V (AC/DC) |
| Relay contact current | - | 9.4A (AC/DC) |

### Contact life

| Item | Value |
|---|---|
| 230VAC, 1A | 800k |
| 230VAC, 9.4A | 100k |
| 24VDC, 0.5A | 2M |
| 24VDC, 9.4A | 300k |

## Troubleshooting

### Cannot Communicate with device
- If the modbus LEDs are flickering, make sure the RelayGuarian and relay share the same settings.
- Active the recovery mode on the device and in the RelayGuardian
- If no communication is established, check the serial adapter communication port
- Check the wriring. Modbus pins cannot be swapped.

### Lost Device ID
1. Send a valid broadcast frame to enter configuration mode.
2. Use the default Device ID (`0`) to reset the device via the reset register.

### Relay Does Not Respond
- Check the watchdog timeout setting to ensure it isn’t triggering prematurely.

---

## FMEA – Modbus Relay Board for CNC Safety

This FMEA analyzes potential failure modes of a Modbus-controlled relay board designed for CNC safety, including load control and emergency stop (E-stop) functionality.
Any failure should result in the CNC stopping by letting go of the estop switch.
<br/>**Note**: The estop must be checked once at the start of operations. This step is done by the Masso CNC device. This relay estop contact is Normally Opened. So when the CNC starts, the relay would be open.
If the relay was to close **after** the Masso had booted, this could be considered an estop test.
Therefore, the relay must be started well before the Masso. This is the case (100ms vs 10s).

The top events to consider are:
1. Lack of dust extraction clogs the work and leads to the cutter breaking.
The operation is done in normally closed and protected condition to safeguard the operator.
Mecanical damage only.
2. Lack of cooling of the spindle leads to spindle overheat.
NTP sensor on the spindle should detect the overheat if wired. Else, the spindle could be damaged.
A fire is unlikely.

| Function | Failure Mode | Effect of Failure | Cause(s) | Detection Method(s) | S | O | D | RPN | Recommended Action(s) |
|---|---|---|---|---|---|---|---|-----|---|
| Control Load Relays  | Relay not switching | Load not powered leading to CNC or cutter damage | Relay failure, dry joint | Feedback circuit | 8 | 4 | 3 | 96  | Add redundant relay check, use industrial-grade relays |
| Control Load Relays  | Relay stuck ON | Unsafe load activation | Relay contact welding | Feedback circuit | 9 | 3 | 4 | 108 | Use a forced conduit relay and read back the status of the relay  |
| E-Stop Relay | E-stop not triggered | CNC continues in unsafe state | Logic fault, relay failure | Self-test, watchdog | 10| 2 | 3 | 60  | Use safety-rated relay, periodic self-test |
| Power Monitoring | Under/over voltage undetected | Damage to CNC or relay | Sensor failure, ADC error | Voltage threshold check | 9 | 3 | 4 | 108 | Add voltage sensing, calibration check |
| Power Converter | Converter fails | Relay board unpowered, failsafe triggers | Component failure | Relay state monitoring | 7 | 4 | 2 | 56  | Use robust converter, thermal protection. =<br/>Power the estop relay from the mains power |
| Modbus Communication | Loss of communication | E-stop triggered, CNC halts | Cable fault, EMI, software crash | Timeout watchdog | 6 | 5 | 2 | 60  | Loss of comms indicates the bus is damaged or the master has crashed. esop. |
| Test of the esop switch | estop relay opens and close cycle is considered a estop switch test  | False E-stop test | Non cold reboot of the firmware | Analysis of the reboot cause | 8 | 3 | 3 | 72  | Do not allow the modbus board to reboot |

### Legend
- **S (Severity)**: 1 (low) to 10 (catastrophic)
- **O (Occurrence)**: 1 (rare) to 10 (frequent)
- **D (Detection)**: 1 (certain detection) to 10 (undetectable)
- **RPN (Risk Priority Number)**: S × O × D

### Summary
Focus should be placed on:
- Improving detection of stuck or failed relays
- Enhancing voltage monitoring redundancy
- Ensuring robust communication and feedback diagnostics

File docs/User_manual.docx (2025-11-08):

Modbus Relays Device with EStop

User Manual

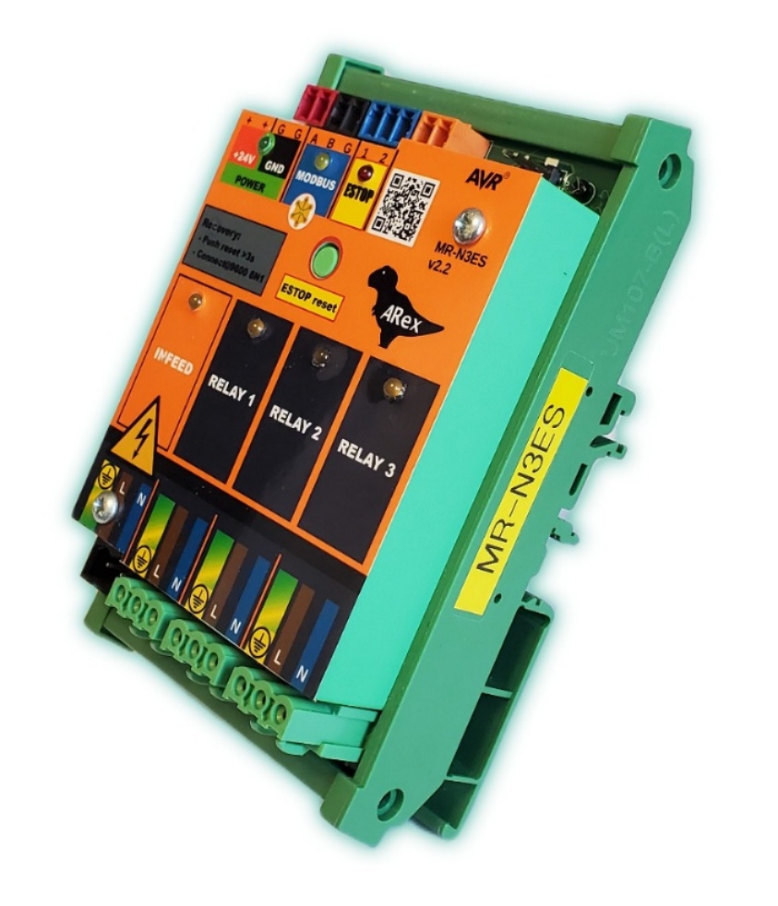
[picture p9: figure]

Software@arreckx.com

Arex

France

# 1 Glossary

Term | Description
Modbus RTU | A serial communication protocol used to transmit information between electronic devices over RS485. RTU stands for "Remote Terminal Unit."
Relay | An electromechanical switch controlled electronically to open or close circuits.
Failsafe Mode | A safety condition where the system defaults to a secure state (e.g. relays open) in case of failure.
EStop (Emergency Stop) | A safety mechanism to immediately halt operations in response to faults or hazards.
Recovery Mode | Mode activated to reset or reconfigure the device, typically when communication settings are lost.
Locate Mode | Mode used to visually identify a specific device within a group by flashing LEDs.
Relay Filter | A programmable delay to enforce minimum ON/OFF durations to prevent rapid toggling.
Projected State | The intended next state of a relay after the current filtered cycle completes.
Flash Memory | Non-volatile storage that retains data even after power-off; used in boot-time integrity checks.
Brown-Out Detector | Hardware that monitors power supply voltage to prevent operation during insufficient voltage levels.
Watchdog Timer | A safety timer that triggers EStop if Modbus communication fails within a preset duration.
Infeed Voltage | The supply voltage delivered to the relay module, monitored for faults.
Diagnostic Code | A numeric code reporting fault details used for troubleshooting.
RelayGuardian | Software tool used to configure and manage the device over Modbus.
Holding Register | Writable Modbus register storing device configuration parameters.
Coil Register | Modbus register used to control relays directly by writing ON/OFF commands.

# 2 Abbreviations

Abbreviation | Meaning
RTU | Remote Terminal Unit
RS485 | Recommended Standard 485 (serial interface)
DC | Direct Current
AC | Alternating Current
LED | Light Emitting Diode
Tx | Transmit (Modbus LED indicator)
Rx | Receive (Modbus LED indicator)
RPN | Risk Priority Number
S/O/D | Severity / Occurrence / Detection (FMEA metrics)
EEPROM | Electrically Erasable Programmable Read-Only Memory
MSB/LSB | Most/Least Significant Byte
UINT32 | Unsigned 32-bit Integer
MODBUS | Modular Data Bus (communication protocol)
lsb | Least Significant Bit
msb | Most Significant Bit
LSB | Least Significant Byte
MSB | Most Significant Byte

# 3 Introduction

This project features a MODBUS-RTU controlled relay device with emergency stop, infeed measurements, monitoring and failsafe modes. It is aimed at industrial systems such as CNC or equivalent.

This document provides a description of the operations of the device.

## 3.1 Device identification

The device identification is MB-R3ES.

The hardware and the software are released together; the GitHub TAG references this design uniquely.

All engineering data can be downloaded from GitHub: www.github.com/adarwoo/modbus_relay.

## 3.2 Features summary

This relay goes beyond a single Modbus relay and is packed with features:

1. Standard DIN Rail mountable PCB
2. 3 relays - up to 9.4A at 250V per output
  - Individual filtering for ON and OFF cycles for each relay
3. Modbus RTU v1.1_r3 compliant
  - Coil control commands 01, 05 and 15
  - Input registers command 04
  - Holding registers commands 03, 06 and 16
  - Support for encapsulated interface transport (MEI) type 13
  - Device identification 17
4. Operational integrity
  - Uses safety relays with forced conduits, 10.10⁶ operations, reinforced isolation and position read back.
  - Galvanically isolated infeed voltage measurement with monitoring
  - Communication watchdog
5. Emergency Stop (EStop) management.
  - Safeguards relay operations
    - Relay failure
    - Infeed voltage fault (over, under, inverted, DC vs AC)
    - Communication loss
    - Application crash/corruption
  - Externally controlled by the Modbus server
    - Pulsed EStop
    - Resettable EStop with a push button
    - Terminal EStop for terminal cases
6. Operations statistics
  - Number of cycles
  - Running time
  - Fault codes
7. Diagnostics over Modbus
  - Infeed highs and lows
  - Infeed type and level
  - EStop causes and diagnostic.

# 4 Operations overview

Operations are performed over a Modbus RTU communication bus.

A push button can be used on the device:

1. to reset an EStop when allowed.
2. to activate the recovery mode. (See Chapter 8 - Recovery mode)

## 4.1 System startup

The device starts with the EStop on (failsafe on power loss). The device self-checks and starts measuring the infeed. If all conditions are correct, the EStop is cleared.

This takes < 1s in normal conditions.

## 4.2 Relay polarity and failsafe position

The relay’s failsafe position is 'OFF' - that is - the contact is opened. If the device loses power, the relays open the contacts at once - turning off the load. Security prevents them turning back-on in case of a crash.

The control of the relay always works with a positive polarity, so writing '1' will close the relay - and energize the load.

## 4.3 Basic operations

The relay works like any Modbus coil-based device, by writing the coil registers. Each relay can be controlled individually, turned ON, OFF. The relays can also be controlled in bulk.

See Coil registers chapter for details operations.

## 4.4 Relay Cycles Filtering

Filtering can be configured to enforce minimum durations for the relay’s closed and open states.

The closed-state filter defines how long the relay will remain closed before it can change state.

For example, a closed-state filter of 2 seconds ensures the relay remains closed for at least 2 seconds.

The open-state filter works the same way, guaranteeing a minimum open time.

Any command received during a filtered period is queued and will take effect once the filter duration ends—unless a newer command overrides it.

Example:
A relay has a minimum closed-cycle time of 4 seconds and no filter on the open state.

1. The relay receives a close command → it closes and the closed-cycle timer starts.
2. After 1 second, an open command is received. This command is stored as the next state, but the relay remains closed until the minimum 4-second period is complete.
3. After 3 more seconds (4 total), the relay opens because the closed-cycle has ended.
4. A new close command is received → the relay closes immediately, since the open state has no filter.
5. After 2 seconds, another open command arrives. The relay stays closed because the 4-second minimum closed-cycle has not elapsed.
6. One second later (3 seconds into the cycle), another close command arrives. The relay is already closed, so nothing changes.
7. Two seconds later (5 seconds total in the closed state), an open command is received. The relay opens immediately, since the closed cycle has exceeded the 4-second filter duration.

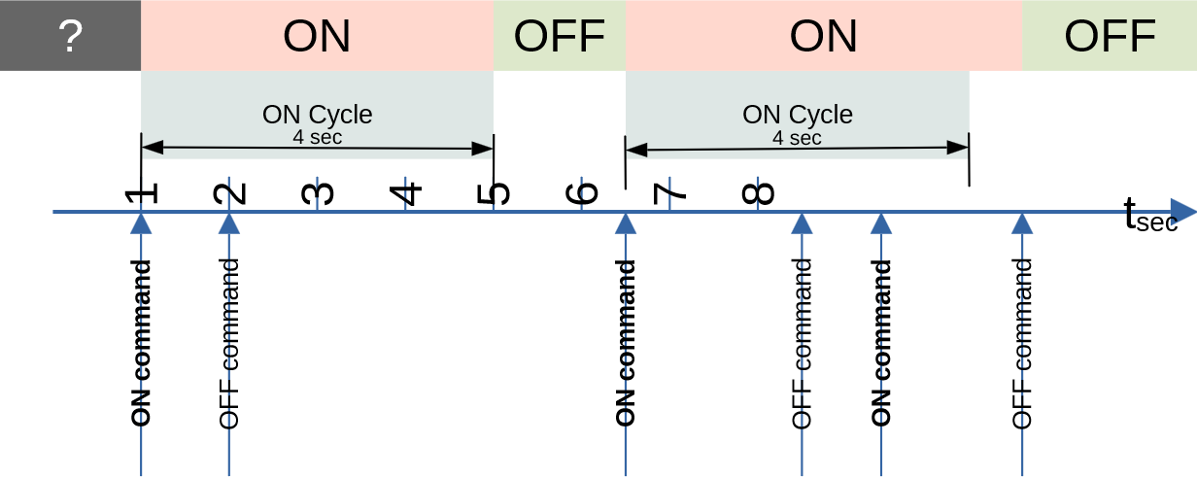
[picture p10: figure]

⚠️ WARNING: When reading the status of a relay, the actual physical position is returned, not the projected position.

# 5 System Health Monitoring

This device distinguishes itself from simpler models by its ability to monitor the health of the system and to halt operations by opening an EStop relay.

The active elements being monitored and/or measured are:

1. Device integrity
2. Modbus communications
3. Infeed voltage, which is the upstream supply voltage.
4. Proper operation of the relays

## 5.1 Device integrity monitoring

The device monitors itself to guarantee proper execution. All memories are verified:

1. The flash memory integrity is verified at every boot.
2. The RAM is tested once on boot-up.
3. The EEprom storage has a checksum.
4. The CPU power supply is monitored by the brown-out-detector to safeguard the EEprom integrity.
5. A failsafe exists which activates the EStop if the power supply was to fail.
6. The execution is monitored; an application crash will EStop the device.

Any terminal failure leads to the EStop being activated.

## 5.2 Modbus communication monitoring

The device monitors the activity of the Modbus RS485 link, and through this, the health of the Modbus server. This monitoring activity can be configured to trigger an EStop condition.

📝 NOTE: The bus is considered active if frames addressed to the device are received at least once in the configured watchdog duration.

❗ IMPORTANT: For good operation, it is recommended to read the register 30009 (Status) periodically, at least twice during the configured watchdog duration.

## 5.3 Infeed monitoring

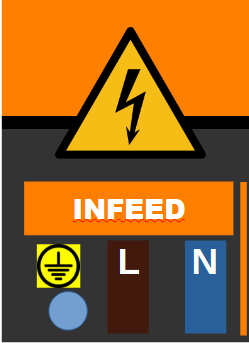
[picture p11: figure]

The module measures the infeed voltage of the relay and the type of infeed (AC vs DC). The AC measurement is the approximate RMS value. The input signal is expected to be a 50Hz or 60Hz supply. Other frequencies will result in undefined behavior.

The last measured value, but also the lowest and highest measured values are accessible over the Modbus network. Additional Modbus registers allow resetting those values during investigations.

When configuring the infeed as DC type, the negative/GND/0V must be connected to 'N' and the positive to 'P'. If this is not the case, the device will immediately trigger an EStop condition.

The in-feed measurement can be used to trigger an EStop on:

1. Polarity inversion for DC configuration
2. Incorrect type (AC vs DC) of the infeed
3. Undervoltage: The infeed voltage is lower than a configured threshold.
4. Overvoltage: The infeed voltage is higher than a configured threshold

Infeed faults can also control the relays based on individual relay configuration.

## 5.4 Relay health monitoring

All the relays are equipped with a position verification which is backed mechanically using a forced conduit. If a relay fault is detected:

1. The relay coil is de-energized, and the relay should become open.
2. An EStop condition is triggered.

The faulty relay must be isolated by disabling it in the configuration to clear the EStop.

The faulty relay should then be replaced.

# 6 Locate mode

This mode allows locating a specific device in setups using more than one relay device.

When activated, the device LEDs will alternate every two seconds between:

1. Fast flash to be easily identified
2. Normal state to get on-going indications

The locate mode is activated by a dedicated Modbus command. It is ended by either a Modbus command, or by pressing the 'EStop reset' push button.

# 7 Recovery mode

The recovery mode is used to change the communication parameters and can be used to recover a device with unknown settings.

The recovery mode is entered by keeping the 'EStop reset' push button pressed for more than 3 seconds until the EStop LEDs flash fast.

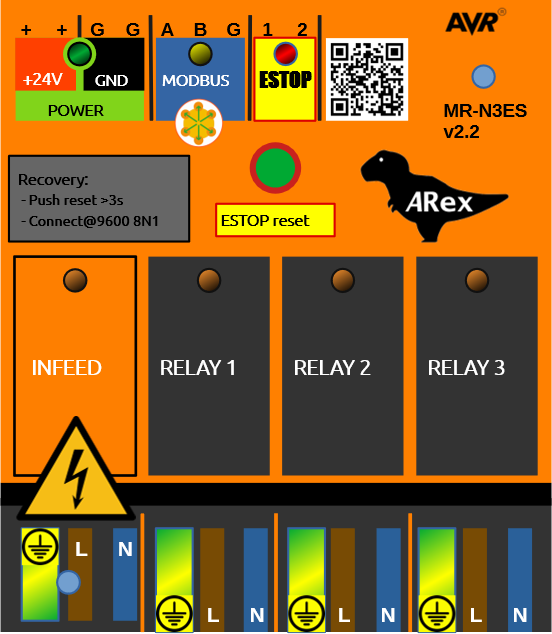
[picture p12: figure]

The device communication setting immediately becomes:

1. Slave ID : 248 ; This value is reserved in the Modbus standard, so no other devices should use it.
2. Baud rate: 9600
3. Serial setup: 8N1 - 8bits, no parity and 1 stop bit.

You may use any Modbus master application to reconfigure the device, or use the RTUGuardian[^1] application using the following procedure:

1. Start the RTUGuardian application.
2. Make sure the communication port is properly set up in the RelayGuardian. The connection status should be OK
3. Issue a scan command in the RTUGuardian to make sure the RS485 adapter sends the data. The device Modbus LEDs should blink
4. If this is not the case, check the Modbus is plugged correctly in the PC and the comm port is the correct one.
5. If devices are identified during the scan, click the 'locate' icon one device at time to see if it is the right one.
6. Otherwise, start the recovery:
  - Push the relay 'EStop reset' push button until the EStop LED is flashing
  - In the RTUGuardian application, press ‘CTRL+R’ to activate the recovery.
7. The device should be identified. The module is being recovered.
8. In the recovery window, configure the communication settings
  - The RTUGuardian settings are imported automatically
  - You can change the settings and apply them to the guardian
9. Hit one of the ‘Apply’ buttons The guardian takes the relay out of recovery mode automatically. You're all set!

📝 NOTE: The recovery mode keeps on-going relay operations.

💡 TIP: The recovery mode can also be ended by pressing the 'EStop reset' push button for another 3s.

# 8 EStop

The device EStop relay opens the circuit when the device is in EStop condition.

## 8.1 Triggering of the EStop

The EStop condition is the result of:

1. Detecting an internal failure; (relay, crash, infeed, supply, ...)
2. Through external command over Modbus

### 8.1.1 External EStop command

The Modbus master can issue an EStop command. This external EStop can be:

1. Pulsed EStop. The EStop relay opens briefly stopping the system. There is reset required.
2. Resettable EStop. The relay remains opened until the EStop condition is cleared.
3. Terminal EStop. Only a power cycle or remote reset will clear the EStop condition.

## 8.2 Clearing the EStop

The EStop can only be cleared once the root cause has been remediated.

Clearing the EStop condition can be done:

- Automatically when the EStop is triggered remotely in pulsed mode.
- Manually, but pushing the EStop reset button.
- Remotely over the Modbus network. (See register 40101).

In all cases, the EStop condition can be read over the Modbus network.

❗ IMPORTANT: When the device is in both locate and EStop mode, the first push on the EStop reset clears the locate mode and the second clears the EStop.

## 8.3 Relays in EStop

The following EStop conditions will impact the relay position:

Condition | Impact | Filtering | Recovery
Application crash | Opens | Bypassed | EStop clear
In-feed polarity inversion | Opens | Bypassed | The polarity must be fixed then clear the EStop
In-feed threshold | Configurable Register 40021 | Bypassed | EStop clear
External EStop | No impact | - | No impacts. The Modbus master can still control the relays
Modbus communication loss | Configurable Register 40022 | Applied | EStop clear
Individual relay failure | Opens | Bypassed | The faulty relay must be disabled, then clear the EStop

# 9 LEDs

The module features LEDs to see the device operation and faults easily.
Each LED may serve multiple purposes.

For detailed LED states, see:

1. EStop LED
2. Infeed LED
3. Modbus LEDs
4. Relay LEDs

## 9.1 Boot

During boot, for the first 2 seconds, all LEDs are lit. This allows checking for a faulty LED. The fault LED remains on if a persistent fault condition is detected during the auto-test.

## 9.2 Locate function

To help locate a relays device, a Modbus locate command can be sent. See Locate mode.

In locate mode, a sequence is repeated with all LEDs flashing fast (10Hz) for 2 seconds and display their normal value for the next 2.

The EStop reset push button can be pressed to end the locate cycle, or a new Modbus command can be sent.

## 9.3 Recovery mode

This only affects the Fault LED which flashes at 2Hz.

## 9.4 EStop LED

The EStop LED state is as follows:

State | Description
Off | Normal operations
On | Terminal mode Either the device failed self-tests, or an external terminal EStop was issued. The EStop is active.
Flashes at 2Hz | Resettable fault with EStop It can be reset remotely or with the push button once the cause has been remediated.
Flashes fast 10Hz | The recovery mode is active
ON for 2s | Shows a pulsed EStop condition received from the Modbus master

When a resettable EStop is in progress, any other LEDs flashing is an indication of the source of the EStop. See other LEDs for interpretation.

## 9.5 Infeed Led

The infeed LED provides visual information about the infeed voltage.

State | Description
Off | Infeed voltage is < 10V (AC or DC)
On | Infeed voltage detected
Flashes | Triggering an EStop
Pulsed | Wrong type or outside of the range

☢️ CAUTION: The Infeed LED is for indication only. You must assume voltage is always present.

## 9.6 Modbus LED

The Modbus LED shows activity on the Modbus RS485 network, received or transmitted data will pulse the LED for 20ms.

The LED is lit during boot and is used for recovery and identification modes.

### 9.6.1 Activity LED

The following table summarizes the ‘activity’ LED states

State | Description
Off | No data is being received/transmitted
Blinks | Data is being received/transmitted on the bus. The data may or may not be addressed to the device.
Flashes | Has triggered and EStop. Could be a command or watchdog

## 9.7 Relays LED

Each relay has a dedicated LED. The LED reports the status of the relay is corresponds to.

The LED status is as follows:

State | Description
Off | The relay is in the OFF state
On | The relay is in the ON state
Flashes | Detected a faulty relay and triggered an EStop
Pulsed | The relay is disabled

# 10 Modbus communications and registers

The product uses Modbus RTU over a half-duplex RS485 (https://www.modbus.org/docs/Modbus_over_serial_line_V1.pdf). It allows communication up-to 115200 baud to the device.

The Modbus registers are grouped into:

1. Coil Registers
2. Input Registers
3. Holding Registers
4. Device Control Registers

For communication settings, see Communication Settings.

📝 NOTE: By convention, all relays are indexed from 0.
Therefore, the device relay label 'Relay 1' is indexed at 0.

## 10.1 Device Identification

The device supports Modbus 1.1b Report Slave ID function and Read Device Identification functions.

### 10.1.1 Report Slave ID

The function 17 is often used to scan for Modbus RTU devices on a bus.

The device implements this function.

📝 NOTE: The Run Status indicator always reads as ON (0xFF)
The Slave ID is ‘MBR3-ES_<model_name>’.

### 10.1.2 Encapsulated Transport Interface

The function 43 with a Modbus Encapsulated Interface Type 14 (0x2B) is supported to query device information.

Object ID | Object Name / Description | Type | Category | Possible value
0x00 | VendorName | ASCII String | Basic | ARex
0x01 | ProductCode | ASCII String | | MBR3-ES
0x02 | MajorMinorRevision | ASCII String | | 2.0
0x03 | VendorUrl | ASCII String | Regular | www.github.com/adarwoo
0x05 | ModelName | ASCII String | | 1.0c
0x80 | Private Object 1 Recovery mode | ASCII String | Extended | <ReCoVeRy>;<version>;<offset> Example: ReCoVeRy;1;0x0000 This object indicates that the device supports the Recovery Mode protocol. The first field is a fixed tag (ReCoVeRy), the second field defines the recovery schema version, and the third field indicates the start address (in hexadecimal) of the communication setup registers used during recovery.
0x81 | Private Object 0 Number of relays | ASCII String | | 1-16 Example: 3

📝 NOTE: The device reports its Recovery Support capability through Object 0x80, but the active recovery state is inferred from the device using Modbus address 248. This address is reserved and used exclusively while the device is in Recovery Mode.

## 10.2 Coil registers

The relay coils can be accessed from 0 (Relay 1) up to relay 31. Coils can be written and read at will.

The device supports the following function codes:

- 01: Read coils (https://www.modbustools.com/modbus.html) Read from 1 to 32 contiguous status of coils. Coils in the response message are packed as one per bit of a byte, 1=On and 0=Off. If the requested quantity of coils is not a multiple of 8, zeros are padded in the final byte.
- 05: Write single coil (https://www.modbustools.com/modbus.html) Write a single output to either On (1) or Off
- 15: Write multiple coils (https://www.modbustools.com/modbus.html) Force each coil in a sequence of coils to either On or Off

❗ IMPORTANT: Relays operations are not affected by the EStop Unless a relay is faulty or disabled, a command of that relay will always be executed, but could be delayed by one of the relay cycle filters

⚠️ WARNING: Attempts to write individually a disabled relay with the function 05 will generate a slave_device_failure (4) error. Attempts to turn ON a disabled or faulty relay as part of the function 15 will also generate a slave device failure error. You can still use function 15 providing that the faulty/disabled relay is commanded to OFF.

### 10.2.1 Details of the function 05: Write single coil.

The following values can be used:

Value | Meaning
0x0000 | This specific 16-bit value is the Modbus standard representation for "OFF".
0xFF00 | This specific 16-bit value is the Modbus standard representation for "ON" when writing to a coil.
0xAA00 | This value toggles the coil at the end of the cycle

## 10.3 Input registers

Input registers are read-only registers used to report information about the device. The registers have been grouped so they can easily be accessed. Reserved values read as 0, therefore, it is possible to read all the input registers in a single command.

Only the function 04: Read input registers (https://www.modbustools.com/modbus.html) is supported to read registers.

### 10.3.1 Status & Monitoring

Use function 04: Read input registers (https://www.modbustools.com/modbus.html) is supported to read registers.

Modbus Address | Hex value | Access | Description | Values
30009 | 0x0008 | R | Status | 0: Device is operational 1: Device is in EStop. A reset is possible 2: Device in terminal EStop
30010-30011 | 0x0009-0x000A | R | Running minutes | UINT32 0 – (2³²-1)
30012 | 0x000B | R | Actual infeed voltage type | Reports the type of infeed voltage detected 0: Measured AC/DC voltages are below 10V 1: DC 2: AC
30013 | 0x000C | R | Current infeed voltage | 1/10 volts : 0-3000
30014 | 0x000D | R | Infeed lowest voltage | Returns the lowest measured infeed voltage until now in 1/10th of volts. This value can be reset with the command: - 40102 - Reset measurements
30015 | 0x000E | R | Infeed highest voltage | Same as 30014, but returns the highest
30016 | 0x000F | R | Device Health | Bit 0: One or more relays have faults. Check individual relay status. Bit 2: Infeed polarity inverted Bit 3: Incorrect infeed voltage type Bit 4: Infeed voltage is under Bit 5: Infeed voltage is over Bit 8: Application crash detected Bit 9: EEprom recovered Bit 10: Supply voltage failure Bits 8 and above are cleared by a power cycle or reset command only.

30017

0x0010

R

Last or on-going EStop root cause

Bit 0: Relay Fault

Bit 1: Modbus communication lost
The communication watchdog reported a lack of communication

Bit 2: Infeed polarity inversion

Bit 3: Unexpected Infeed voltage type
An incorrect voltage type was detected. AC in vs DC expected for example.

Bit 4: Infeed voltage under
The voltage has gone below the configured threshold

Bit 5: Infeed voltage over
The voltage has gone over the configured threshold

Bit 6: Command
A Modbus command was issued to place the device in EStop

Bit 8: Application crash
The device is recovering from an application crash

Bit 9: EEprom corrupted
The EEprom memory was corrupted and was reset.

Bit 10: Supply voltage failure
A power failure caused the device to restart

This register is not cleared when the EStop is reset, allowing for post crisis diagnostic, or checking the cause of pulsed resets.
30017 | 0x0011 | R | Diagnostic code | Diagnostic code of the EStop condition. This register contains the last external diagnostic code supplied with the EStop
30018–30024 | 0x0012–0x0017 | — | Reserved

### 10.3.2 Relay Diagnostics & Statistics

The status of each relay is accessible, and well as their individual number of cycles. A cycle is defined as a change of relay state during operation (exclude power loss transitions).

The address space is structured to expand up to 16 relays for other variants of devices.

Use function 04: Read input registers (https://www.modbustools.com/modbus.html) is supported to read registers.

Modbus Address | Hex value | Access | Description | Values
30025 | 0x0018 | R | Relay 1 diagnostic | 0=OK 1=Faulty 2=Disabled
30026-30027 | 0x0019-0x001A | R | Relay 1 number of cycles | Unsigned 32-bits 0-(2³²-1)
30028 | 0x001B | R | Relay 2 diagnostic | 0=OK 1=Faulty 2=Disabled
30029-30030 | 0x001C-0x001D | R | Relay 2 number of cycles | Unsigned 32-bits 0-(2³²-1)
30031 | 0x001E | R | Relay 3 diagnostic | 0=OK 1=Faulty 2=Disabled
30032-30033 | 0x001F-0x0020 | R | Relay 3 number of cycles | Unsigned 32-bits 0-(2³²-1)

⚠️ WARNING: Reading passed the last supported relay will generate an illegal data address error.

💡 TIP: For generic software, the number of available relays can be read in input registers 30004.

## 10.4 Holding registers

Holding registers hold values that can be read or written. The hold configuration details. They are grouped by functions. It is possible to read all the holding registers with 1 command as the reserved values will read as one. Writing these registers is restricted to prevent misbehavior.

⚠️ WARNING: Reserved values cannot be written and will generate an error.

### 10.4.1 Supported function codes.

The following function codes are supported:

3. 03 - Read Holding Registers (https://www.modbustools.com/modbus.html) Reads the values of one or more holding registers. Commonly used to retrieve configuration or control values stored in the device.
4. 06 - Write Single Register (https://www.modbustools.com/modbus.html) Writes a single value to a specific holding register. Used for updating configuration or control parameters.
5. 16 - Write Multiple Registers (https://www.modbustools.com/modbus.html) Writes a whole configuration group at once. This is only available for writing the communication settings.

⚠️ WARNING: Do not issue the function 04: Read input registers when reading holding registers as the memory addresses of both types overlaps.

Other functions codes such as 23 (Read/Write Multiple Registers) are not supported.

### 10.4.2 Communication Settings

This group of registers allow configurations to configure the communication settings of the relay.

❗ IMPORTANT: These registers are write-protected. You must activate the 'recovery' mode to change them, by pressing the 'EStop Reset' button for more than 3 seconds.

📝 NOTE: You must use function 16 - Write Multiple Registers, writing registers 40001 to 40004 at once. Once a write is done, the device comes out of recovery mode and applies the changes right away.

Use function 16: Write Multiple Registers (https://www.modbustools.com/modbus.html) is supported to read registers.

Use function 03 - Read Holding Registers (https://www.modbustools.com/modbus.html) to read these registers.

Modbus Address | Hex Value | Access | Description | Factory value | Values
40001 | 0x0000 | RW | device address | 44 | [1-247]
40002 | 0x0001 | RW | Baud rate | 5 | 0=300 1=600 2=1200 3=2400 4=4800 5=9600 6=19200 7=38400 8=57600 9=115200
40003 | 0x0002 | RW | Parity | 0 | 0=None 1=Odd 2=Even
40004 | 0x0003 | RW | Stop bits | 1 | 1=1 Stop bit 2=2 stop bits
40005–40008 | 0x0004–0x0007 | R | Reserved

### 10.4.3 Power Infeed Configuration

Configure the expected in-feed voltage.

📝 NOTE: You must use function 16 - Write Multiple Registers, writing registers 40009 to 40011 at once.

Use function 16: Write Multiple Registers (https://www.modbustools.com/modbus.html) is supported to read registers.

Use function 03 - Read Holding Registers (https://www.modbustools.com/modbus.html) to read these registers.

Modbus Address | Hex Value | Access | Description | Factory Value | Values
40009 | 0x0008 | RW | Infeed voltage type | 1 | 0=No monitoring 1=DC 2=AC
40010 | 0x0009 | RW | Infeed lower voltage threshold | 100 | 1/10 volts [0-3000]
40011 | 0x000A | RW | Infeed upper voltage threshold | 3000 | 1/10 volts [0-3000]
40012–40016 | 0x000B–0x000F | R | Reserved | 0

### 10.4.4 Safety Logic Configuration

Monitored values can optionally control EStop. It is also possible to set the behavior of each relay on these optional EStop conditions.

⚠️ WARNING: The registers must be written individually. Function 16 is not supported

Use function 06 - Write Single Register (https://www.modbustools.com/modbus.html) to write these registers.

Use function 03 - Read Holding Registers (https://www.modbustools.com/modbus.html) to read these registers.

Modbus Address | Hex Value | Access | Description | Factory Value | Values
40017 | 0x0010 | RW | Activate EStop on undervoltage | 0 | 0=no 1=yes
40018 | 0x0011 | RW | Activate EStop on overvoltage | 0 | 0=no 1=yes
40019 | 0x0012 | RW | Activate EStop on incorrect type of supply voltage. Example: AC detected with DC configured | 0 | 0=no 1=yes
40020 | 0x0013 | RW | Activate EStop on number of seconds without Modbus frame received | 0 | 0=Off 1-65535: Number of seconds
40021 | 0x0014 | RW | Mask to open relays on electrical infeed fault, bypassing filtering. When an infeed fault is detected, the relay state is immediately opened or left unchanged based on this value. A bit at 1 in the mask indicates the relay should open on a fault detection. The lsb (bit 0) masks the relay at index 0, the msb (bit 15) masks the relay at index 15 | 0 | 0-0xFFFF Example: 0: No relays are affected 5 (binary 110): Relays at position 1 and 2 are set to open 0xFFFF: All relays are set to open
40022 | 0x0015 | RW | Mask to open relays on Modbus communication loss fault. When a loss in communication is detected, the relay projected state¹ is opened. | 0 | See 40021
40023–40024 | 0x0016–0x0017 | R | Reserved

¹The projected state is the state of a relay once the on-going filter cycle is complete.

### 10.4.5 Relays Configuration

This group allows configuring the individual relays.

⚠️ WARNING: The registers must be written individually. Function 16 is not supported.

Use function 06 - Write Single Register (https://www.modbustools.com/modbus.html) to write these registers.

Use function 03 - Read Holding Registers (https://www.modbustools.com/modbus.html) to read these registers.

Modbus Address | Hex Value | Access | Description | Factory default | Values
40025 | 0x0018 | RW | Relay 1 config | 0=Enabled, no filter | msb bits [15-8] are for the closed filter. lsb bits [7-0] are the opened filter. The value 0xFFFF disables the relay. The ON and OFF filters values are given in 1/10 of seconds from 0 to 254 (0 to 25.4s) Example: 0x0132 The ON state is guaranteed to last at least 100ms, whilst the OFF state is guaranteed to last at least 50 x 1/10s = 5s after a ON. See relay operations.
40026 | 0x0019 | RW | Relay 2 config | 0=Enabled, no filter | Same as relay 1 config
40027 | 0x001A | RW | Relay 3 config | 0=Enabled, no filter | Same as relay 1 config
40025+N¹ | 0x0018+N | RW | Relay N config | 1=Enabled, no filter | Same as relay 1 config

¹ N is the relay index [0... (Number of relay-1)]

⚠️ WARNING: Read or writing a non-supported relay will generate an error.

## 10.5 Device control registers

These registers share the holding registers mapping address space but are write-only. This group of registers allows controlling the EStop and the device.

📝 NOTE: These registers are write-only. The function 03: Read multiple registers is not available for this group. Function 16 - Write Multiple Registers is not available. The registers must be written individually.

Use function 06 - Write Single Register (https://www.modbustools.com/modbus.html) to write these registers.

Modbus Address | Hex Value | Access | Description | Values
40101 | 0x0064 | W | Set/Reset the EStop | ESTOP_CTRL See note 1
40102 | 0x0065 | W | Zero measurements. Allow re-measuring min and max | 0xAA55
40103 | 0x0066 | W | Identify the device. Fast flash all the LEDs to identify the device | 0 = Turn off 1 = Turn on
40104 | 0x0067 | W | Reset configuration to factory default and reboot | 0x178C
40105 | 0x0068 | W | Exit recovery mode and apply comms settings | 0xAA55
40106 | 0x0069 | W | Reset the device | 0xAA55

Note 1: See the format below.

### 10.5.1 EStop control.

The following table documents the type ESTOP_CTRL used to control the EStop.

Byte | Function | Values
MSB | Type of EStop | 0x00: Reset the EStop if possible. Returns an error if the EStop could not be reset 0x11: Pulsed EStop. Create a 4 second EStop pulse 0x22: Resettable EStop mode. The EStop can be reset by pushing the EStop reset button 0xFF: Terminal EStop. Only a reset will clear the EStop (Register 40103)
LSB | External Code | 0 to 255.Arex

# 11 Electrical and mechanical characteristics

For relay data, refer to the datasheet of the SiSF2 relay (https://www.ermec.com/catalogos/2021/ELESTA/sisf2_-_en.pdf) for detailed data. Note that both contacts of the relay are paired as one.

## 11.1 Electrical characteristics

Item | Min | Max
Device supply voltage | 18 VDC | 30 VDC
Infeed voltage | - | 250V (AC/DC)
Relay contact current | - | 9.4A (AC/DC)

## 11.2 Contact life

Item | Value
230VAC, 1A | 800k
230VAC, 9.4A | 100k
24VDC, 0.5A | 2M
24VDC, 9.4A | 300k

## 11.3 Troubleshooting

### 11.3.1 Cannot Communicate with device.

6. If the Modbus LEDs are flickering, make sure the RelayGuardian and relay share the same settings.
7. Active the recovery mode on the device and in the RelayGuardian
8. If no communication is established, check the serial adapter communication port.
9. Check the wiring. Modbus pins cannot be swapped.

### 11.3.2 Lost Device ID

1. Send a valid broadcast frame to enter configuration mode.
2. Use the default Device ID (0) to reset the device via the reset register.

### 11.3.3 Relay Does Not Respond

10. Check the watchdog timeout setting to ensure it isn’t triggering prematurely.

# 12 FMEA – Modbus Relay Board for CNC Safety

This FMEA analyzes potential failure modes of a Modbus-controlled relay board designed for CNC safety, including load control and emergency stop (E-stop) functionality. Any failure should result in the CNC stopping by letting go of the estop switch. Note: The EStop must be checked once at the start of operations. This step is done by the Masso CNC device. This relay EStop contact is Normally Opened.
When the CNC starts, the relay will be open. If the relay was to close after the Masso had booted, this could be considered an estop test. Therefore, the relay must be started well before the Masso. This is the case (100ms vs 10s).

The top events to consider are:

1. Lack of dust extraction clogs the work and leads to the cutter breaking. The operation is done in normally closed and protected condition to safeguard the operator. Mechanical damage only.
2. Lack of cooling of the spindle leads to spindle overheating. NTP sensor on the spindle should detect the overheat if wired. Else, the spindle could be damaged. Fire is unlikely.

Function | Failure Mode | Effect of Failure | Cause(s) | Detection Method(s) | S | O | D | RPN | Recommended Action(s)
Control Load Relays | Relay not switching | Load not powered leading to CNC or cutter damage | Relay failure, dry joint | Feedback circuit | 8 | 4 | 3 | 96 | Add redundant relay check, use industrial-grade relays
Control Load Relays | Relay stuck ON | Unsafe load activation | Relay contact welding | Feedback circuit | 9 | 3 | 4 | 108 | Use a forced conduit relay and read back the status of the relay
E-Stop Relay | E-stop not triggered | CNC continues in unsafe state | Logic fault, relay failure | Self-test, watchdog | 10 | 2 | 3 | 60 | Use safety-rated relay, periodic self-test
Power Monitoring | Under/over voltage undetected | Damage to CNC or relay | Sensor failure, ADC error | Voltage threshold check | 9 | 3 | 4 | 108 | Add voltage sensing, calibration check
Power Converter | Converter fails | Relay board unpowered, failsafe triggers | Component failure | Relay state monitoring | 7 | 4 | 2 | 56 | Use robust converter, thermal protection. =Power the estop relay from the mains power
Modbus Communication | Loss of communication | E-stop triggered, CNC halts | Cable fault, EMI, software crash | Timeout watchdog | 6 | 5 | 2 | 60 | Loss of comms indicates the bus is damaged or the Modbus master has crashed. EStop.
Test of the EStop switch | EStop relay opens and close cycle is considered a estop switch test | False E-stop test | Non cold reboot of the firmware | Analysis of the reboot cause | 8 | 3 | 3 | 72 | Do not allow the Modbus board to reboot

## 12.1 Legend

11. S (Severity): 1 (low) to 10 (catastrophic)
12. O (Occurrence): 1 (rare) to 10 (frequent)
13. D (Detection): 1 (certain detection) to 10 (undetectable)
14. RPN (Risk Priority Number): S × O × D

## 12.2 Summary

Focus should be placed on:

15. Improving detection of stuck or failed relays
16. Enhancing voltage monitoring redundancy
17. Ensuring robust communication and feedback diagnostics

[^1] https://github.com/adarwoo/rtu_guardian

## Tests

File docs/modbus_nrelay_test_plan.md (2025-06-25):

# ✅ Test Plan for Modbus N-Relay Device with EStop

This document describes the test scenarios and test cases to verify compliance with the specification requirements.

---

## 🧪 Test Scenario 1: Relay Control via Modbus

### Test Case 1.1: Write Single Coil - ON
**Setup**: Relay 1 configured as enabled, no filtering  
**Operation**: Send Modbus function 05 with value `0xFF00` to coil 0  
**Expected Result**: Relay 1 closes (ON), relay LED turns ON

### Test Case 1.2: Write Single Coil - OFF
**Setup**: Relay 1 previously ON  
**Operation**: Send Modbus function 05 with value `0x0000` to coil 0  
**Expected Result**: Relay 1 opens (OFF), relay LED turns OFF

### Test Case 1.3: Write Single Coil - Toggle
**Setup**: Relay 1 initially ON  
**Operation**: Send Modbus function 05 with value `0xAA00` to coil 0  
**Expected Result**: Relay 1 toggles to OFF

### Test Case 1.4: Write to Disabled Relay
**Setup**: Relay 2 configured as disabled (0xFFFF)  
**Operation**: Send Modbus function 05 to coil 1  
**Expected Result**: Modbus returns slave device failure

---

## 🧪 Test Scenario 2: Infeed Voltage Monitoring

### Test Case 2.1: In-Range Voltage
**Setup**: Infeed set to 230V AC, configured range 200–240V  
**Operation**: Apply voltage  
**Expected Result**: No EStop triggered, infeed LED ON

### Test Case 2.2: Undervoltage Fault
**Setup**: Infeed set to 180V, configured lower threshold = 200V, undervoltage EStop enabled  
**Operation**: Apply voltage  
**Expected Result**: EStop triggered, EStop LED 2Hz blink, infeed LED slow blink

### Test Case 2.3: Overvoltage Fault
**Setup**: Infeed set to 250V, upper threshold = 240V, overvoltage EStop enabled  
**Operation**: Apply voltage  
**Expected Result**: EStop triggered, EStop LED 2Hz blink, infeed LED long ON short OFF

---

## 🧪 Test Scenario 3: Communication Watchdog

### Test Case 3.1: No Watchdog Trigger
**Setup**: Watchdog set to 5s, register 30009 read every second  
**Operation**: Let system run for 10s  
**Expected Result**: No EStop triggered

### Test Case 3.2: Watchdog Timeout
**Setup**: Watchdog set to 5s, stop communication  
**Operation**: Wait 6s  
**Expected Result**: EStop triggered, EStop cause = 2, diagnostic = 5

---

## 🧪 Test Scenario 4: EStop Functionality

### Test Case 4.1: Pulsed EStop
**Setup**: Normal state  
**Operation**: Write `0x1101` to register 40101  
**Expected Result**: EStop active for 4s, resets automatically

### Test Case 4.2: Resettable EStop
**Setup**: Normal state  
**Operation**: Write `0x2202` to register 40101  
**Expected Result**: EStop active until reset button pressed

### Test Case 4.3: Terminal EStop
**Setup**: Normal state  
**Operation**: Write `0xFF03` to register 40101  
**Expected Result**: EStop active, only reset via power cycle

---

## 🧪 Test Scenario 5: Recovery Mode

### Test Case 5.1: Enter Recovery
**Setup**: Device in normal mode  
**Operation**: Hold reset button > 3s  
**Expected Result**: LEDs flash, device uses slave ID 248, 9600 baud, 8N1

### Test Case 5.2: Modify Comm Settings
**Setup**: Device in recovery  
**Operation**: Write to registers 40001–40004 using function 16  
**Expected Result**: Settings updated, device exits recovery mode

---

## 🧪 Test Scenario 6: LED Indicators

### Test Case 6.1: Boot Test
**Setup**: Device powered OFF  
**Operation**: Power ON  
**Expected Result**: All LEDs ON for 2 seconds

### Test Case 6.2: Identify Command
**Setup**: Normal state  
**Operation**: Write `1` to register 40103  
**Expected Result**: All LEDs flash at 10Hz for 1s

---

## 🧪 Test Scenario 7: Relay Health & Diagnostics

### Test Case 7.1: Relay Cycle Counter
**Setup**: Relay 1 configured, OFF  
**Operation**: Toggle ON/OFF 5 times  
**Expected Result**: Register 30026–30027 increases by 5

### Test Case 7.2: Faulty Relay
**Setup**: Simulate stuck relay  
**Operation**: Toggle relay  
**Expected Result**: EStop triggered, LED blinks 2Hz, diagnostic code = relay index

---

## 🧪 Test Scenario 8: Factory Reset & Configuration

### Test Case 8.1: Factory Reset
**Setup**: Custom settings applied  
**Operation**: Write `0x178C` to register 40104  
**Expected Result**: Device resets, default settings restored

---

## 🧪 Test Scenario 9: Unsupported Conditions

### Test Case 9.1: Unsupported Relay Index
**Setup**: Device with 3 relays  
**Operation**: Access coil or register for relay 4  
**Expected Result**: Illegal data address error

### Test Case 9.2: Overlapping Read to Wrong Register Type
**Setup**: Normal state  
**Operation**: Read input register using function 03  
**Expected Result**: Unexpected data or error

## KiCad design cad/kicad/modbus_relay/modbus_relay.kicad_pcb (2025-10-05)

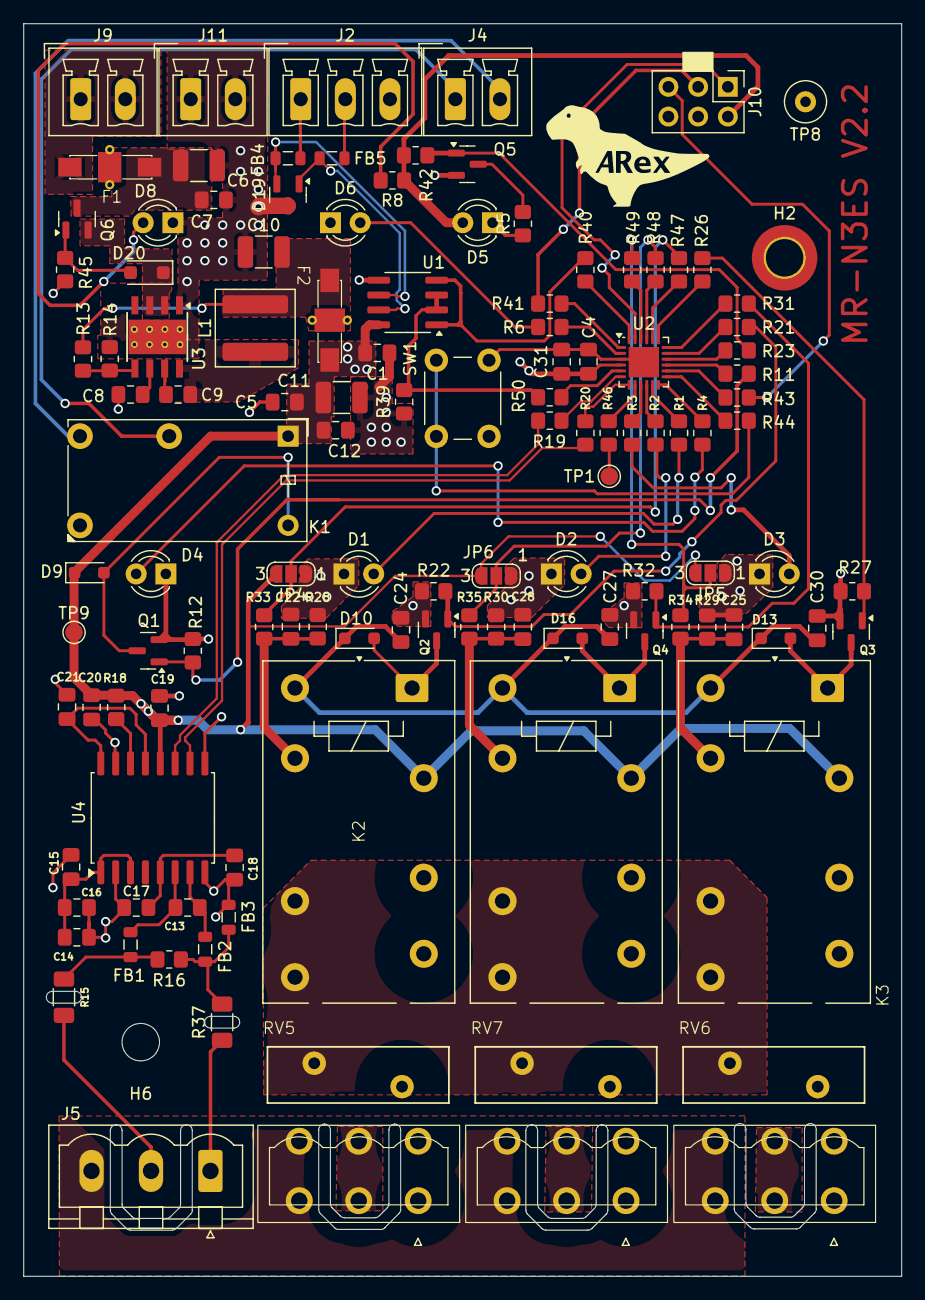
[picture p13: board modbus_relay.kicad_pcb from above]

Board: 2 copper layers, 75.0 x 107.0 mm, 124 parts (0 on the bottom side), 86 nets.

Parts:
C1, C4, C9, C12, C16, C18, C21, C22, C25, C28: 100n; C_0805_2012Metric_Pad1.18x1.45mm_HandSolder
C5, C8, C14, C19, C24, C27, C30: 1u; C_0805_2012Metric_Pad1.18x1.45mm_HandSolder
C6, C10: 10u 50v; C_1210_3225Metric_Pad1.33x2.70mm_HandSolder
C7: 220nF; C_0805_2012Metric_Pad1.18x1.45mm_HandSolder
C11: 47u; C_1210_3225Metric_Pad1.33x2.70mm_HandSolder
C13, C15, C17, C20: 1n; C_0805_2012Metric_Pad1.18x1.45mm_HandSolder
C31: 10n; C_0805_2012Metric_Pad1.18x1.45mm_HandSolder
D1, D2, D3, D4, D5, D6: G; LED_D3.0mm
D8: LED; LED_D3.0mm
D9: 1J; D_SOD-323_HandSoldering
D10, D13, D16: BAS16; D_SOD-323_HandSoldering
D19: SM712_SOT23; SOT-23
D20: BZT52B12; D_SOD-123F
F1, F2: Murata_NFM61R
FB1, FB2, FB3: FerriteBead; L_0805_2012Metric
FB4, FB5: FerriteBead_Small; L_0805_2012Metric
H2: MountingHole_Pad; MountingHole_3.2mm_M3_DIN965_Pad_TopBottom
H6: MountingHole; MountingHole_3.2mm_M3
J2: Screw_Terminal_01x03; PhoenixContact_MCV_1,5_3-G-3.81_1x03_P3.81mm_Vertical
J4, J9, J11: Screw_Terminal_01x02; PhoenixContact_MCV_1,5_2-G-3.81_1x02_P3.81mm_Vertical
J5: Screw_Terminal_01x03; PhoenixContact_MSTBVA_2,5_3-G-5,08_1x03_P5.08mm_Vertical
J7, J8, J12: 1785955; CONN_1943548
J10: Conn_02x03_Odd_Even; PinHeader_2x03_P2.54mm_Vertical
JP4, JP5, JP6: SolderJumper_3_Open; SolderJumper-3_P1.3mm_Open_RoundedPad1.0x1.5mm_NumberLabels
K1: Relay_SPDT; Relay_SPDT_Finder_32.21-x000
K2, K3, K4: SISF212
L1: 10uH; L_Bourns_SRP6060FA
Q1, Q2, Q3, Q4, Q5: BSS138; SOT-23
Q6: AO3401A; SOT-23
R1, R2, R3, R4, R5, R6, R8: 680; R_0805_2012Metric_Pad1.20x1.40mm_HandSolder
R11, R21, R23, R26, R31: 22; R_0805_2012Metric_Pad1.20x1.40mm_HandSolder
R12, R22, R27, R32, R39, R42: 10k; R_0805_2012Metric_Pad1.20x1.40mm_HandSolder
R13: 100k; R_0805_2012Metric_Pad1.20x1.40mm_HandSolder
R14: 24k9; R_0805_2012Metric_Pad1.20x1.40mm_HandSolder
R15, R37: 1M6; R_1206_3216Metric_Pad1.30x1.75mm_HandSolder
R16, R18, R45: 10K; R_0805_2012Metric_Pad1.20x1.40mm_HandSolder
R19, R20: 1K; R_0805_2012Metric_Pad1.20x1.40mm_HandSolder
R28, R29, R30, R33, R34, R35, R40, R41, R43, R44, R46, R47, R48, R49, R50: 332; R_0805_2012Metric_Pad1.20x1.40mm_HandSolder
RV5, RV6, RV7: 471K; MOV471
SW1: SW_Push; SW_PUSH_6mm_H4.3mm
TP1: TestPoint_Probe; TestPoint_Pad_D1.5mm
TP8: TestPoint; TestPoint_Loop_D3.50mm_Drill0.9mm_Beaded
TP9: TestPoint; TestPoint_Pad_D1.5mm
U1: LT1785AxS8; SOIC-8_3.9x4.9mm_P1.27mm
U2: ATtiny3227-M; QFN-24-1EP_4x4mm_P0.5mm_EP2.6x2.6mm
U3: LMR33630ADDA; Texas_HSOP-8-1EP_3.9x4.9mm_P1.27mm_ThermalVias
U4: AMC3330; SOIC-16W_7.5x10.3mm_P1.27mm

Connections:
+24V: F1.1, J9.1, J9.2
+RS485_B: FB5.1, J2.2
-RS485_A: FB4.1, J2.1
/FILT+: D19.1 (A1), FB5.2, U1.7 (B)
/FILT-: D19.2 (A2), FB4.2, U1.6 (A)
/Power supply/VIN: D20.1 (K), Q6.2 (S), U3.2 (VIN), U3.3 (EN)
/power sensing/OUTN: R20.1, U4.10 (OUTN)
/power sensing/OUTP: R19.1, U4.11 (OUTP)
DIAG: R18.2, U4.14 (DIAG)
ES_1: J4.1, K1.11
ES_2: J4.2, K1.14
Earth: J5.3, J7.5, J7.6, J8.5, J8.6, J12.5, J12.6
GND: C1.2, C4.2, C5.2, C6.2, C7.2, C8.2, C10.2, C11.2, C12.1, C19.1, C20.1, C21.1, C22.2, C24.2, C25.2, C27.2, C28.2, C30.2, C31.2, D1.1 (K), D2.1 (K), D3.1 (K), D4.1 (K), D6.1 (K), D8.1 (K), D19.3 (common), F1.2, F2.2, H2.1, J2.3, J10.6, J11.1, J11.2, JP4.1 (A), JP5.1 (A), JP6.1 (A), Q1.2 (S), Q2.2 (S), Q3.2 (S), Q4.2 (S), Q5.2 (S), R12.2, R14.1, R22.2, R27.2, R28.2, R29.2, R30.2, R32.2, R39.2, R45.1, SW1.2, TP8.1, U1.5 (GND), U2.3 (GND), U2.25 (GND), U3.1 (GND), U3.9 (GND), U4.9 (GND), U4.15 (DCDC_GND)
GNDPWR: C14.1, C15.1, C16.1, C17.1, C18.1, FB3.2, U4.2 (DCDC_HGND), U4.8 (HGND)
ISO_IN+: R19.2, U2.6 (AIN5)
ISO_IN-: R20.2, U2.7 (AIN6)
LED_MAINS: R4.1, U2.12 (PB4)
LED_RELAY_1: R1.1, U2.11 (PB5)
LED_RELAY_2: R2.1, U2.10 (PB6)
LED_RELAY_3: R3.1, U2.9 (PB7)
LED_RX: R6.1, U2.2 (1,WO)
MAINS_L: J5.2, K2.23, K2.33, K3.23, K3.33, K4.23, K4.33, R15.1, RV5.1, RV6.1, RV7.1
MAINS_N: J5.1, J7.1, J7.2, J8.1, J8.2, J12.1, J12.2, R37.2
unnamed: C10.1, F2.1, L1.2, R13.2
unnamed: C22.1, K2.11, R28.1, R33.2
unnamed: C25.1, K3.11, R29.1, R34.2
unnamed: C28.1, K4.11, R30.1, R35.2
unnamed: D1.2 (A), R1.2
unnamed: D2.2 (A), R2.2
unnamed: D3.2 (A), R3.2
unnamed: D4.2 (A), R4.2
unnamed: D5.1 (K), R5.1
unnamed: D6.2 (A), R6.2
unnamed: D8.2 (A), R8.2
unnamed: D9.2 (A), K1.A2, Q1.3 (D)
unnamed: D10.2 (A), K2.A2, Q2.3 (D)
unnamed: D13.2 (A), K3.A2, Q3.3 (D)
unnamed: D16.2 (A), K4.A2, Q4.3 (D)
unnamed: D20.2 (A), Q6.1 (G), R45.2
unnamed: FB1.1, R15.2, R16.1
unnamed: FB2.1, FB3.1, R16.2, R37.1
unnamed: J10.1, U2.23 (~RESET)
unnamed: J10.3, R41.2
unnamed: J10.5, R43.2
unnamed: Q1.1 (G), R11.2, R12.1
unnamed: Q2.1 (G), R21.2, R22.1
unnamed: Q3.1 (G), R26.2, R27.1
unnamed: Q4.1 (G), R31.2, R32.1
unnamed: Q5.3 (D), R5.2
unnamed: Q5.1 (G), R23.2, R42.2
unnamed: C6.1, C7.1, F1.3, Q6.3 (D)
unnamed: R44.1, SW1.1
unnamed: R46.1, TP1.1
unnamed: R39.1, R50.1, U1.2 (~RE), U1.3 (DE)
unnamed: R40.1, U1.1 (RO), U1.4 (DI)
unnamed: R40.2, U2.24 (TXD1)
unnamed: R41.1, U2.1 (PA2)
unnamed: R50.2, U2.5 (XDIR1)
unnamed: R46.2, U2.8 (PA7)
unnamed: R43.1, U2.14 (TXD0)
unnamed: R44.2, U2.13 (PB3)
unnamed: R47.1, U2.20 (PC3)
unnamed: R48.1, U2.21 (PC4)
unnamed: R49.1, U2.22 (PC5)
unnamed: C9.1, U3.7 (BOOT)
unnamed: R13.1, R14.2, U3.5 (FB)
unnamed: C9.2, L1.1, U3.8 (SW)
unnamed: C8.1, U3.6 (VCC)
unnamed: C21.2, U4.13 (LDO_OUT), U4.16 (DCDC_IN)
unnamed: C14.2, C15.2, C16.2, U4.1 (DCDC_OUT), U4.3 (HLDO_IN)
unnamed: C17.2, C18.2, U4.5 (HLDO_OUT)
unnamed: C13.1, FB2.2, U4.7 (INN)
unnamed: C13.2, FB1.2, U4.6 (INP)
RELAY_CHECK_1: JP4.2 (C), R33.1, R47.2
RELAY_CHECK_2: JP6.2 (C), R35.1, R48.2
RELAY_CHECK_3: JP5.2 (C), R34.1, R49.2
RELAY_CMD_1: R21.1, U2.17 (PC0)
RELAY_CMD_2: R31.1, U2.18 (PC1)
RELAY_CMD_3: R26.1, U2.19 (PC2)
RELAY_OUT_1: J7.3, J7.4, K2.24, K2.34, RV5.2
RELAY_OUT_2: J12.3, J12.4, K4.24, K4.34, RV7.2
RELAY_OUT_3: J8.3, J8.4, K3.24, K3.34, RV6.2
VCC: C1.1, C4.1, C5.1, C11.1, C12.2, C19.2, C20.2, C31.1, D5.2 (A), D9.1 (K), F2.3, J10.2, JP4.3 (B), JP5.3 (B), JP6.3 (B), K1.A1, K2.12, K3.12, K4.12, R8.1, R18.1, R42.1, TP9.1, U1.8 (VCC), U2.4 (VCC), U4.12 (VDD)
VIN: C24.1, C27.1, C30.1, D10.1 (K), D13.1 (K), D16.1 (K), K2.A1, K3.A1, K4.A1
~ESTOP: R11.1, U2.15 (PB1)
~LED_FAULT: R23.1, U2.16 (PB0)

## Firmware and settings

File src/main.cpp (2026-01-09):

/*
 * Relay modbus device main entry point.
 * The relays are initialised by the static constructor
 */
#include <ulog.h>
#include <asx/reactor.hpp>

#include "counters.hpp"
#include "relay.hpp"
#include "push_button.hpp"
#include "leds.hpp"
#include "infeed.hpp"
#include "net.hpp"
#include "estop.hpp"
#include "state.hpp"

#include <chrono>


int main()
{
   ULOG_MILE("Modbus relay application starting!");

   /*
    * Initialize all modules
    * The order determines the reactor handler priorities
    */

   // Ready network handling, the modbus and the UART
   net::init();

   // Ready the relay control
   relay::init();

   // Ready the ingress measurement system
   infeed::init();

   // Ready the push button
   sw::init();

   // Initialize the state manager
   state::init();

   // Initialise the configuration system
   config::init();

   // Ready the estop
   estop::init();

   // Ready the stats
   counter::init();

   // Initialise the LEDs
   led::init();

   // Run the reactor/scheduler
   asx::reactor::run();
}

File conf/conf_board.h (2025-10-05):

#pragma once
/**
 * Defines all I/Os of the board using Pin
 * Compatible with C and C++ use (ioport.h or asx/ioport.hpp)
 * In C++, the namespace asx::ioport must be used
 */

/************************************************************************/
/* Debug pins                                                           */
/* Pin DEBUG_REACTOR_IDLE is available on the uPDI connector on Pin 3   */
/* UART0 TxD is available on the uPDI connector on Pin 5                */
/************************************************************************/
#undef  DEBUG_REACTOR_IDLE          // No pin for this
#define DEBUG_REACTOR_BUSY          IOPORT(A, 2)
#define UART0_TXD                   IOPORT(B, 2)
#define UART1_TXD                   IOPORT(A, 1)
#define UART1_XDIR                  IOPORT(A, 4)


/************************************************************************/
/* Alert pin                                                            */
/* This is connected to the LED_FAULT and shared for other purposes     */
/************************************************************************/
#define ES_COMMAND                  IOPORT(B, 1)
#define ALERT_OUTPUT_PIN            IOPORT(B, 0)

/************************************************************************/
/* Modbus LEDs                                                          */
/************************************************************************/

// The Rx LED is driven by the TimerB1
#define LED_MODBUS                  IOPORT(A, 3)

/************************************************************************/
/* Relay I/Os                                                           */
/************************************************************************/
#define LED_A                       IOPORT(B, 5)
#define LED_B                       IOPORT(B, 6)
#define LED_C                       IOPORT(B, 7)

#define RELAY_A                     IOPORT(C, 0)
#define RELAY_B                     IOPORT(C, 1)
#define RELAY_C                     IOPORT(C, 2)

#define CHECK_A                     IOPORT(C, 3)
#define CHECK_B                     IOPORT(C, 4)
#define CHECK_C                     IOPORT(C, 5)

/************************************************************************/
/* In-Feed sensing                                                      */
/************************************************************************/
#undef INFEED_DIAG                  // No pin for this
#define INFEED_LED                  IOPORT(B, 4)

/************************************************************************/
/* Push button                                                          */
/************************************************************************/
#define PUSH_BUTTON                 IOPORT(B, 3)

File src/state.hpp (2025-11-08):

#pragma once
/**
 * @file state.hpp
 * @brief Manages the device state including recovery mode, locate mode, and fault modes.
 *
 * This module provides functions to check and set the device's operational modes,
 * including recovery mode, locate mode, and fault modes.
 */
#include <avr/wdt.h>
#include <cstdbool>
#include <chrono>

#include <asx/reactor.hpp>

#include "leds.hpp"
#include "net.hpp"

namespace state {
   /**
    * Global fault indicator
    * Represents various fault conditions in the system.
    * Bit 0: One or more relays have faults. Check individual relay status.
    * Bit 2: Infeed polarity inverted
    * Bit 3: Incorrect infeed voltage type
    * Bit 4: Infeed voltage is under
    * Bit 5: Infeed voltage is over
    * Bit 8: Application crash detected
    * Bit 9: EEprom recovered
    * Bit 10: Supply voltage failure
   */
   namespace fault {
      constexpr uint16_t relay_fault             = 1 << 0;
      constexpr uint16_t infeed_polarity_inverted = 1 << 2;
      constexpr uint16_t infeed_bad_type         = 1 << 3;
      constexpr uint16_t infeed_under_voltage    = 1 << 4;
      constexpr uint16_t infeed_over_voltage     = 1 << 5;
      constexpr uint16_t external_estop          = 1 << 6;
      constexpr uint16_t app_crash               = 1 << 8;
      constexpr uint16_t eeprom_recovered        = 1 << 9;
      constexpr uint16_t supply_voltage_failure  = 1 << 10;
   }

   namespace detail {
      inline bool recovery_mode = false;
      inline bool locate_mode = false;

      inline auto on_reset_network = asx::reactor::bind(
         [] { net::reset_settings(); }
      );

      inline uint16_t current_faults{};
   }

   /** Get the current fault indicators */
   inline uint16_t get_faults() {
      return detail::current_faults;
   }

   /** Append a fault indicator */
   inline void append_faults(uint16_t faults) {
      detail::current_faults |= faults;
   }

   /** Clear all fault indicators */
   inline void clear_faults(uint16_t faults) {
      detail::current_faults &= ~faults;
   }

   /** Check if the device is in recovery mode */
   inline bool is_in_recovery_mode() {
      return detail::recovery_mode;
   }

   /** Set the value. Return true on a false->true transition */
   inline void set_recovery_mode(bool _recovery_mode) {
      // Implementation here
      if (detail::recovery_mode != _recovery_mode) {
         detail::recovery_mode = _recovery_mode;

         // Delay through the reactor so the UART can complete any on-going messages
         detail::on_reset_network.delay(std::chrono::milliseconds(20));
         led::refresh();
      }
   }

   /** Check if the device is in locate mode */
   inline bool is_in_locate_mode() {
      // Implementation here
      return detail::locate_mode;
   }

   /** Set the locate mode */
   inline void set_locate_mode(bool locate_mode) {
      detail::locate_mode = locate_mode;
      led::toggle_locate_mode( locate_mode );
   }

   /** Initialize the state manager */
   inline void init() {
      // Watchdog reset check
      if ( RSTCTRL.RSTFR & RSTCTRL_WDRF_bm ) {
         ULOG_ERROR("Application crash detected from watchdog reset");
         append_faults( fault::app_crash );
      }

      // Check the BOD reset flag
      if ( RSTCTRL.RSTFR & RSTCTRL_BORF_bm ) {
         ULOG_ERROR("Application crash detected from brown-out reset");
         append_faults( fault::supply_voltage_failure );
      }
   }
} // End of state namespace

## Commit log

2024-12-15 Switching to gitman
2024-12-16 Adding the KiCad files
    [relay.kicad_pcb, relay.kicad_sch]
2025-01-02 Fixed baud setting. Using a 1/100th value
    [config.cpp, main.cpp]
2025-05-13 Processing of the ingress voltage
2025-05-13 Work in progress. Need to sense the button to switch to the config mode
2025-05-15 New iopiort wired
2025-05-18 Debugging and fixing as test progress
    [conf_board.h, config.cpp, infeed.cpp]
2025-05-19 Picture of the new relay added
2025-05-22 Added front plate graphics
2025-06-03 Work in progress
    [modbus_relay.kicad_pcb, modbus_relay.kicad_sch]
2025-06-07 Added CAD files and bom
    [3mm 16mm.STL, Flex Holder.STL, Flex switch membrane.STL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]
2025-06-07 Added printed files
2025-06-10 Renamed modbus in net to avoid conflict
    [net.cpp]
2025-06-10 Leds are self managed now
2025-06-19 Adding a flow chart for the recovery
2025-06-20 Cleaned directory structure
    [3mm 16mm.STL, Flex Holder.STL, Flex switch membrane.STL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]
2025-06-20 Invert is gone because inverting when the fail safe is to open makes no sense
    [config.cpp, net.cpp]
2025-06-23 Overhaul of the recovery and management of the baud rate and uart
2025-06-25 Added description of the filtering
2025-06-25 Filter is given in 1/10s
2025-06-25 Reworked the relay to include the filtering.
    [config.cpp, infeed.cpp, main.cpp]
2025-07-02 Fixed the filter
2025-07-16 Fixed the board for the ADC to work. Made the AC and DC measurements work. Added ulog
    [conf_board.h, infeed.cpp, main.cpp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]
2025-07-18 Automatic system update
    [connection.kicad_sch, modbus_relay.kicad_pcb, modbus_relay.kicad_sch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]
2025-07-30 Update of kicad and project files
    [connection.kicad_sch, modbus_relay.kicad_pcb, modbus_relay.kicad_sch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]
2025-09-01 Double sided version
    [connection.kicad_sch, modbus_relay.kicad_pcb, modbus_relay.kicad_sch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]
2025-09-07 New PCBs fixed and tested. Clean defs
    [modbus_relay.kicad_pcb, modbus_relay.kicad_sch, relay.kicad_sch]
2025-10-05 Fixing all during tests
    [config.cpp, net.cpp]
2025-10-05 Still debugging. ULog mystery looks fixed (many many many added issues)
    [conf_board.h, estop.hpp, infeed.cpp]
2025-10-13 Cleaned the LED section. Aligning with the code and tests
2025-10-13 Reworking to match documentation. Test ongoing
    [infeed.cpp]
2025-10-13 ULog added to trace
2025-10-13 Init the config to spot boot errors
    [main.cpp]
2025-10-18 Changes follow validation still on-going
    [Flex Holder.STL, Flex switch membrane.STL]
2025-10-19 Fixed the V_IN VIN label issue
    [modbus_relay.kicad_pcb]
2025-11-08 Fixed recovery. Added logs. Working overall
    [main.cpp, net.cpp, state.hpp]
2025-11-12 Switching to ulog component
2025-12-08 Improved front plate
    [relay.kicad_sch]
2026-01-03 Fixed z corssing detect
    [infeed.cpp]
